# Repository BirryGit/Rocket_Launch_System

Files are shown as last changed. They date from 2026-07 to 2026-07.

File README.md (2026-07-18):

# Rocket Launch System
## What this is
This is a system built to launch mid-powered rockets. The system includes an electronic launch box and a rail for guidance. This project is as simple as possible without compromising look or features.
## Why I built it
I am very nearly finished with my mid-powered rocket build. The rocket kit is called Forte. The problem is launching. I need an electric launch system to set off the electric igniter fuse, and I need a rail to guide the rocket until the fins can take over.
## How to launch
The rocket is put in the slot at the end of the rail, then the 30 ft wire is connected to the rocket's fuse. Once you check the continuity LED, you can flip all of the switches and press the launch buttons! 

## BOM
| Name | Use | Quantity | Cost | Link |
| --- | --- | --- | --- | --- |
| M5 Assorted | Connect things | 19 | 1 | [View item](https://www.amazon.com/Fgruh-272PCS-Washers-Assortment-Assorted/dp/B0FGV561HZ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) |
| M5 T-nuts | Connect things to the extrusion | 17 | 1 | [View item](https://www.amazon.com/dp/B07FPLZXTF?th=1) |
| M5 threaded inserts | Add Threads to 3D printed parts | 3 | 1 | [View item](https://www.amazon.com/Fgruh-272PCS-Washers-Assortment-Assorted/dp/B0FGV561HZ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) |
| M5 washers | For connecting blast deflector | 2 | 1 | [View item](https://www.amazon.com/Fgruh-272PCS-Washers-Assortment-Assorted/dp/B0FGV561HZ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) |
| 3/8-16 x 4 in bolts - Full thread | For leveling feet | 4 | -- | Hardware Store |
| 3/8-16 nut | Feet | 8 | -- | Hardware Store |
| 608 bearings | For smooth feet | 4 | 7 | [View item](https://www.amazon.com/dp/B09PKD8QZZ?th=1) |
| 8 mm rod sections 1 in | For feet | 4 | -- | -- |
| Aluminum extrusion (6 ft, 1010) | Vertical launch rail | 1 | 27 | [View item](https://www.automationdirect.com/adc/shopping/catalog/structural_frames_-z-_rails/t-slotted_rails/1010c) |
| Aluminum extrusion (4 ft, 1010) | Base Piece | 1 | 17 | [View item](https://www.automationdirect.com/adc/shopping/catalog/structural_frames_-z-_rails/t-slotted_rails/1010c) |
| Aluminum extrusion (2 ft, 1010) | Base Piece | 2 | 8 | [View item](https://www.automationdirect.com/adc/shopping/catalog/structural_frames_-z-_rails/t-slotted_rails/1010c) |
| Angle brackets | Frame assembly | 8 | 13 | [View item](https://www.amazon.com/gp/product/B0D3DK2K5F?smid=A2UEOQRRCN7NSU&th=1) |
| Epoxy | Gluing | 1 | -- | -- |
| Metal Plate | Blast Deflection | 1 | -- | -- |
| Pelican Case | Electronics Enclosure | 1 | 30 | [View item](https://www.harborfreight.com/2800-weatherproof-protective-case-medium-black-64551.html) |
| Perfboard | Circuit Organization | 1 | 9 | [View item](https://www.amazon.com/gp/product/B0G4QTPVZ8?smid=A291JS3CHS1ENH&psc=1) |
| Guarded toggle switches | Arming Switch | 2 | 17 | [View item](https://www.amazon.com/gp/product/B07T6XJF1T?smid=AVZNWT0O79W01&th=1) |
| Illuminated momentary switches | Launching Switch | 2 | 8 | [View item](https://www.amazon.com/gp/product/B07FKK2CP5?smid=A1THAZDOWP300U&th=1) |
| Latching key switch | Arming Switch | 1 | 13 | [View item](https://www.amazon.com/gp/product/B07L5D7TXF/ref=ox_sc_saved_title_4?smid=A1POY47GM797OI&psc=1) |
| LED | Continuity LED | 1 | 1 | [View item](https://www.amazon.com/300-Pcs-LED-Diode-Assortment/dp/B0F38LJDJB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) |
| Wire | Connecting Stuff | As Needed | -- | [View item](https://www.amazon.com/Fermerry-Stranded-Electric-Tinned-Copper/dp/B089CQHRDT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) |
| Heat-shrink tubing | Insulating wires | As Needed | -- | [View item](https://www.amazon.com/Ginsco-580-pcs-Assorted-Sleeving/dp/B01MFA3OFA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) |
| Solder | Connecting Wires | As Needed | -- | [View item](https://www.amazon.com/Twocorn-no-wash-tin-Lead-Electric-Soldering/dp/B0CP7QHFL6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) |
| 18650 lithium-ion cells | Power supply | 3 | 4 | [View item](https://www.18650batterystore.com/collections/18650-batteries) |
| 3S battery holder/pack | Holding Batteries | 1 | 7 | [View item](https://www.amazon.com/dp/B07KD9JLH3) |
| 3S protection board | Protect Batteries | 1 | 8 | [View item](https://www.amazon.com/gp/product/B07J9NXQ6W?smid=A1IU4FC9F8Y7P1&psc=1) |
| 5 A automotive fuse | Protect Batteries | 1 | 7 | [View item](https://www.amazon.com/182PCS-Fuses-Assortment-Professional-Automotive/dp/B0CRVF1N2S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) |
| 12 AWG two-conductor cable 30 ft | Connecting to Rocket | 1 | 30 | [View item](https://www.amazon.com/gp/product/B0D9Q3T2N2?smid=A2WDNWBHGNQ6N1&th=1) |

# Pictures
Random_Drawing_Test_2026-Jul-08_02-21-21AM-000_CustomizedView4419025138
Random_Drawing_Test_2026-Jul-08_02-35-28AM-000_CustomizedView16103205783_png
Random_Drawing_Test_2026-Jul-08_02-34-44AM-000_CustomizedView13111556628_png
Random_Drawing_Test_2026-Jul-08_02-22-50AM-000_CustomizedView19276960031_png
Random_Drawing_Test_2026-Jul-08_02-22-06AM-000_CustomizedView41604805889_png
knob_Foot_2026-Jul-06_04-47-25AM-000_CustomizedView34800159218_png

Rocket_Box_2026-Jul-13_03-50-51AM-000_CustomizedView18278803360_png
Rocket_Box_2026-Jul-13_03-42-50AM-000_CustomizedView28827289038_png
Rocket_Box_2026-Jul-13_03-42-22AM-000_CustomizedView5518473478_png
Rocket_Box_2026-Jul-13_03-41-57AM-000_CustomizedView34251778762_png

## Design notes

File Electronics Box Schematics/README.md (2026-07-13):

# Bill Of Materials
- Perfboard
- 12 Gauge Wire, 2 Conductors, Copper Wire 30 ft
- 3S 12V 10A 18650 Lithium Battery Protection Board
- 5A Automotive Fuse
- 2 Momentary LED Switches
- 2 aircraft Guard Safety Switches.
- 1 Latching Key Switch
- Soldering Equipment
- Extra Wire for Connecting Switches (Can be smaller)

# Wiring
Wire according to this schematic. The launch fuse is denoted by an LED.
Annotated
Rocket_Schematic

The number of switches on the left will depend on the number of toggle switches you have. There will always be two momentary switches in order to comply with rocketry laws. The other requirement is for a continuity LED to show if the fuse is making a connection. That is the highest LED that is wired straight through the igniter and a resistor. There needs to be a resistor to stop the fuse from going off prematurely. The LEDS built into the buttons are all wired to common ground. The lights on the momentary switch act as an armed indicator. The last law requirement is that you must be a certain distance from the launch. 30 ft of 12-gauge wire handles that. It has to be thick so as not to cause too much voltage drop.

## Power Source
I used 3 18650 batteries connected to a management board that will safely output 12V. I used a 5A automotive fuse to protect the circuit. It is also important to insulate the board overall to stop shorts. If you wanted to, you could also add a voltage tester in parallel, but I didn't do that.

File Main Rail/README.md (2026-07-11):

# Instructions
Things needed for this part of the build
- 1 X 6ft 10 10 Aluminum Extrusion
- 1 X 4ft 10 10 Aluminum Extrusion
- 2 X 2ft 10 10 Aluminum Extrusion
- 4 X Feet Assemblies
- 8 X 10 10 Angle Brackets
- 16 M5 Bolts
- 16 M5 T Nuts
- 1 X Blast Deflector Assembly
- 1 3/8 tap

## Steps
1. Drill and tap holes into 2ft and 4ft extrusions (One in 2ft and two in 4ft) (Close to the end)
2. Connect the bolt of the feet to the thread
3. Epoxy the end of the bolt into the nut of the foot
4. Connect 2ft and 4ft extrusions in an X shape using the angle brackets, bolts, and nuts
5. Connect the main rod in the same way, directly up from the X
  Updated Rocket Launcher v15
  -  (Use bolts in every hole)

6. Make sure the blast deflector is securely installed

# Renderings

Random_Drawing_Test_2026-Jul-08_02-35-28AM-000_CustomizedView16103205783_png
Random_Drawing_Test_2026-Jul-08_02-34-44AM-000_CustomizedView13111556628_png
Random_Drawing_Test_2026-Jul-08_02-22-50AM-000_CustomizedView19276960031_png
Random_Drawing_Test_2026-Jul-08_02-22-06AM-000_CustomizedView41604805889_png
Random_Drawing_Test_2026-Jul-08_02-21-21AM-000_CustomizedView4419025138

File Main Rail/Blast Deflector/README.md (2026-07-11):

# Parts Needed
- 1 Metal Plate with holes
- 1 3D printed Holder
- 3 M5 * 12
- 3 M5 * 8 ish threaded inserts
- 2 M5 Washers
- 1 M5 T nut

# Assembly

1. Insert inserts into two angled holes
2. Screw M5 bolt into hole without insert
3. Screw on T nut lightly
4. Slide Printed Piece down extrusion
5. Once Holder is in position tighten down bolt to keep in place
6. Screw metal plate in with bolts and washers

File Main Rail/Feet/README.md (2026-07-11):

# Parts Needed for each foot
- 1 608 bearing
- 1 about an inch of 8 mm rod (Mine came from an Ender 3 threaded rod)
- 1 3/8 - 16 by 4in Bolt
- Epoxy
- 1 Printed Knob
- 1 Printed Bearing to Bolt
- 1 Printed Rod to Foot
- 1 Printed Foot Part

# Instructions
1. Print pieces without supports
2. Epoxy bolt into knob 3d print
3. Don't Epoxy Bolt until final install
4. Epoxy Bearing into 3d print
5. Press the printed adapter into the printed foot
6. Epoxy the rod into the adapter and bearing (Do not get Epoxy in the bearing!!)

https://github.com/user-attachments/assets/53609e48-8a4e-4a8f-99e5-f7d9c65818e1

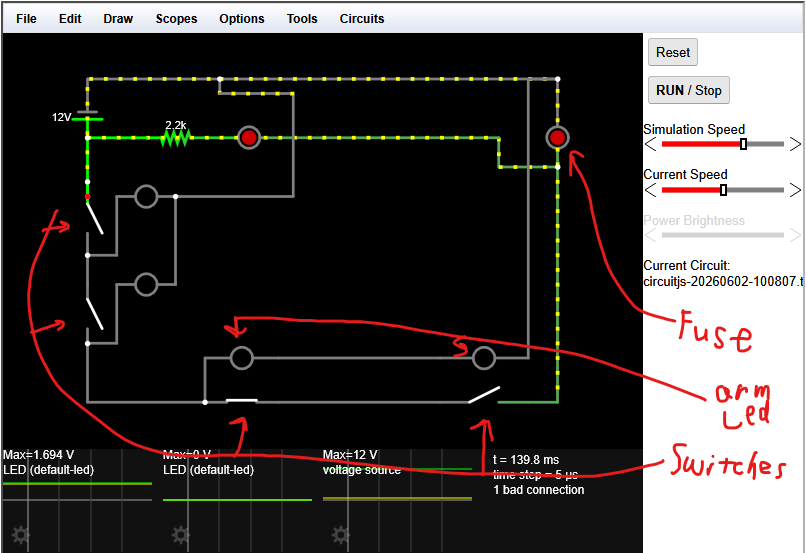
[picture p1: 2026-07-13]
Electronics Box Schematics/Rocket_Schematic.png

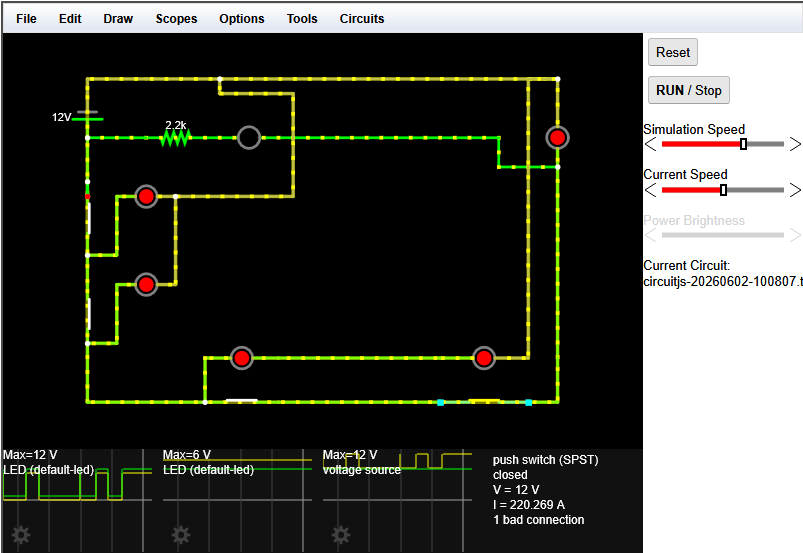
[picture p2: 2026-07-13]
Electronics Box Schematics/Screenshot 2026-07-12 175346.png

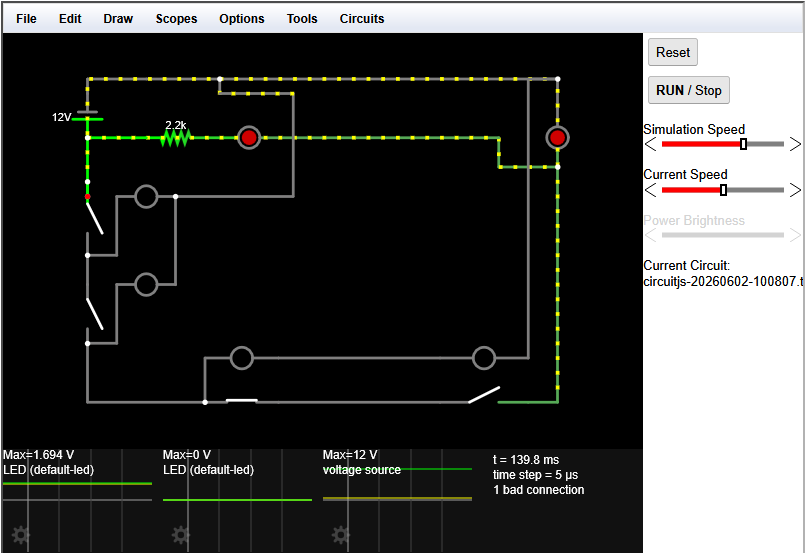
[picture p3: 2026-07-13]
Electronics Box Schematics/Screenshot 2026-06-30 191315.png

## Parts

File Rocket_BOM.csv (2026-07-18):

Name | Use | Quantity | Cost | Link
M5 Assorted | Connect things | 19 | 1 | https://www.amazon.com/Fgruh-272PCS-Washers-Assortment-Assorted/dp/B0FGV561HZ
M5 T-nuts | Connect things to the extrusion | 17 | 1 | https://www.amazon.com/dp/B07FPLZXTF?th=1
M5 threaded inserts | Add Threads to 3D printed parts | 3 | 1 | https://www.amazon.com/Fgruh-272PCS-Washers-Assortment-Assorted/dp/B0FGV561HZ
M5 washers | For connecting blast deflector | 2 | 1 | https://www.amazon.com/Fgruh-272PCS-Washers-Assortment-Assorted/dp/B0FGV561HZ
3/8-16 x 4 in bolts – Full thread | For leveling feet | 4 | -- | Hardware Store
3/8-16 nut | Feet | 8 | -- | Hardware Store
608 bearings | For smooth feet | 4 | 7 | https://www.amazon.com/dp/B09PKD8QZZ?th=1
8 mm rod sections 1 in | For feet | 4 | -- | --
Aluminum extrusion (6 ft, 1010) | Vertical launch rail | 1 | 27 | https://www.automationdirect.com/adc/shopping/catalog/structural_frames_-z-_rails/t-slotted_rails/1010c
Aluminum extrusion (4 ft, 1010) | Base Piece | 1 | 17 | https://www.automationdirect.com/adc/shopping/catalog/structural_frames_-z-_rails/t-slotted_rails/1010c
Aluminum extrusion (2 ft, 1010) | Base Piece | 2 | 8 | https://www.automationdirect.com/adc/shopping/catalog/structural_frames_-z-_rails/t-slotted_rails/1010c
Angle brackets | Frame assembly | 8 | 13 | https://www.amazon.com/gp/product/B0D3DK2K5F?smid=A2UEOQRRCN7NSU&th=1
Epoxy | Gluing | 1 | -- | --
Metal Plate | Blast Deflection | 1 | -- | --
Pelican Case | Electronics Enclosure | 1 | 30 | https://www.harborfreight.com/2800-weatherproof-protective-case-medium-black-64551.html
Perfboard | Circuit Organization | 1 | 9 | https://www.amazon.com/gp/product/B0G4QTPVZ8?smid=A291JS3CHS1ENH&psc=1
Guarded toggle switches | Arming Switch | 2 | 17 | https://www.amazon.com/gp/product/B07T6XJF1T?smid=AVZNWT0O79W01&th=1
Illuminated momentary switches | Launching Switch | 2 | 8 | https://www.amazon.com/gp/product/B07FKK2CP5?smid=A1THAZDOWP300U&th=1
Latching key switch | Arming Switch | 1 | 13 | https://www.amazon.com/gp/product/B07L5D7TXF/ref=ox_sc_saved_title_4?smid=A1POY47GM797OI&psc=1
LED | Continuity LED | 1 | 1 | https://www.amazon.com/300-Pcs-LED-Diode-Assortment/dp/B0F38LJDJB
Wire | Connecting Stuff | As Needed | -- | https://www.amazon.com/Fermerry-Stranded-Electric-Tinned-Copper/dp/B089CQHRDT
Heat-shrink tubing | Insulating wires | As Needed | -- | https://www.amazon.com/Ginsco-580-pcs-Assorted-Sleeving/dp/B01MFA3OFA
Solder | Connecting Wires | As Needed | -- | https://www.amazon.com/Twocorn-no-wash-tin-Lead-Electric-Soldering/dp/B0CP7QHFL6
18650 lithium-ion cells | Power supply | 3 | 4 | https://www.18650batterystore.com/collections/18650-batteries
3S battery holder/pack | Holding Batteries | 1 | 7 | https://www.amazon.com/dp/B07KD9JLH3
3S protection board | Protect Batteries | 1 | 8 | https://www.amazon.com/gp/product/B07J9NXQ6W?smid=A1IU4FC9F8Y7P1&psc=1
5 A automotive fuse | Protect Batteries | 1 | 7 | https://www.amazon.com/182PCS-Fuses-Assortment-Professional-Automotive/dp/B0CRVF1N2S
12 AWG two-conductor cable 30 ft | Connecting to Rocket | 1 | 30 | https://www.amazon.com/gp/product/B0D9Q3T2N2?smid=A2WDNWBHGNQ6N1&th=1

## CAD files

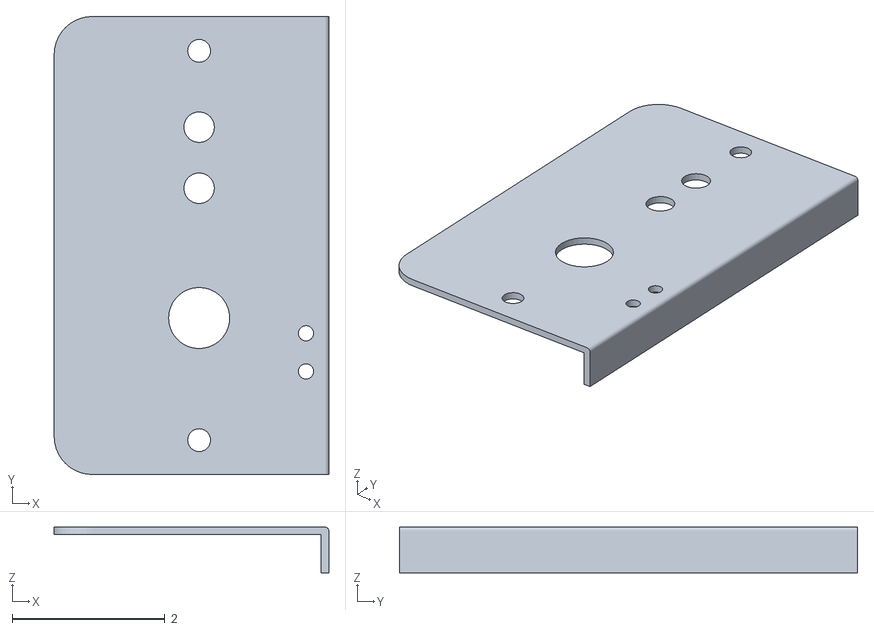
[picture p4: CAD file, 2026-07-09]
Electronics Box 3D Models/Plate_General_Model.stl
3.60 x 6.00 x 0.6

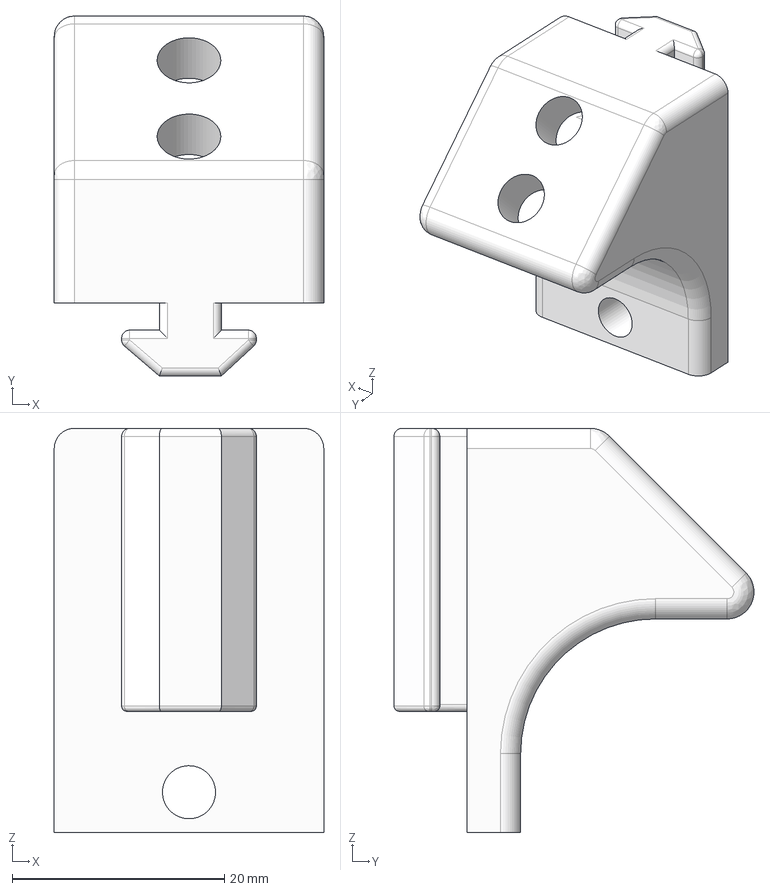
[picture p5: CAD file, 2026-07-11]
Main Rail/Blast Deflector/Blast Deflector Holder v1.step
25.4 x 33.9 x 38.1 mm

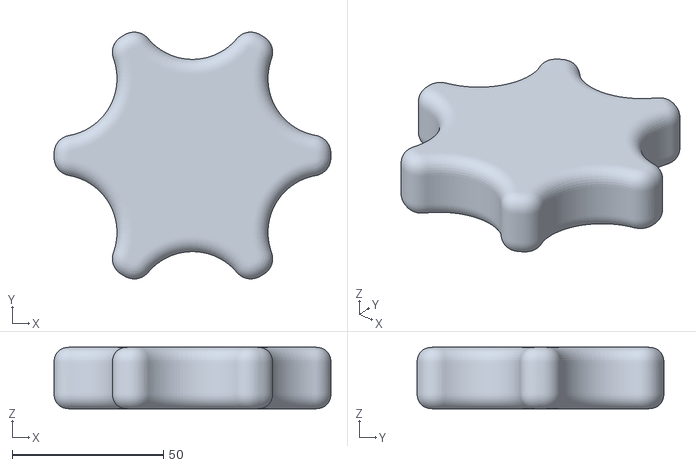
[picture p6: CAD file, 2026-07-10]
Main Rail/Feet/Knob.stl
91.4 x 81.5 x 20.3

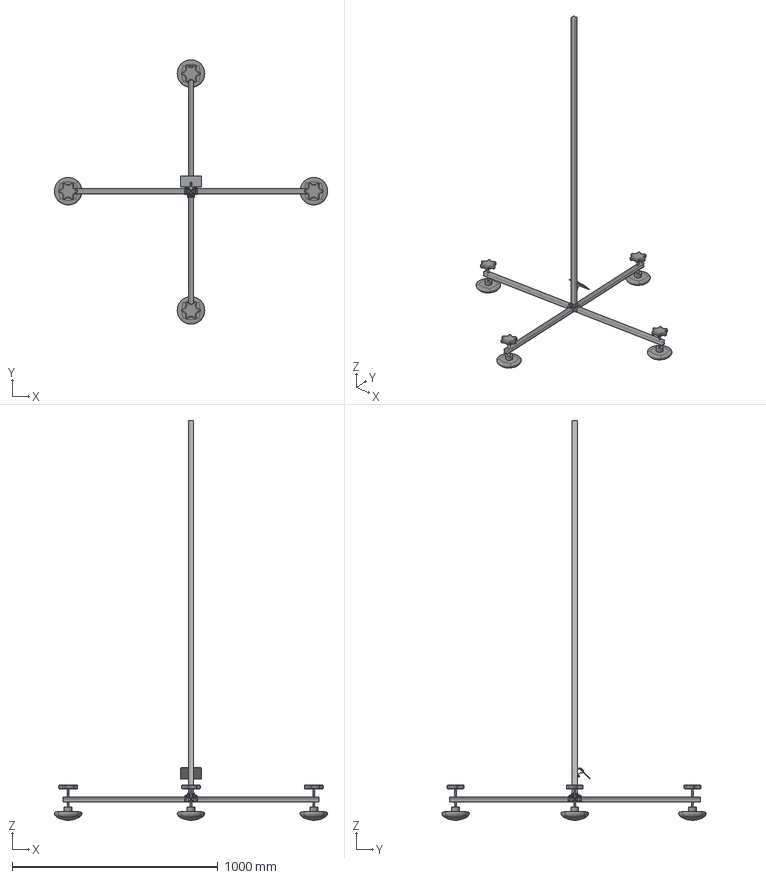
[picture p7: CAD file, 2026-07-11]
Main Rail/Rocket Launch Rail.step
1327.7 x 1284.8 x 1943.6 mm
47065T563_T-Slotted Framing
47065T563_T-Slotted Framing_1
47065T563_T-Slotted Framing_2 x 2
28-600-1Inch x 8
BSHCS ASME B18.3.1M - M5x0.8 x 12 Steel Grade 2 Plain
FPW JIS B 1256 - 5 Steel 100 HV Plain
BSHCS ASME B18.3.1M - M5x0.8 x 12 Steel Grade 2 Black x 3
FPW JIS B 1256 - 5 Steel 100 HV Black x 3
92865A641_Medium-Strength Grade 5 Steel Hex Head Screw x 4
2349K744_Permanently Lubricated Ball Bearing x 4
HN ASME B18.2.2 - 3/8-16 Steel Grade 2H Zinc x 4
Blast Deflector Holder
BSHCS ANSI B18.3.1M - M5x0.8 x 12 Steel Grade 2 Black x 3
BW BS 4320 - M5 E Steel 100 HV Black x 2

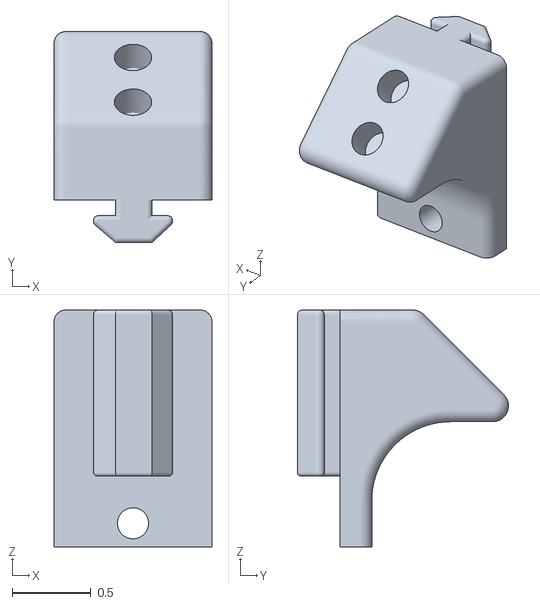
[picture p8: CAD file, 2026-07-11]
Main Rail/Blast Deflector/Blast Plate Print.stl
1.00 x 1.34 x 1.50

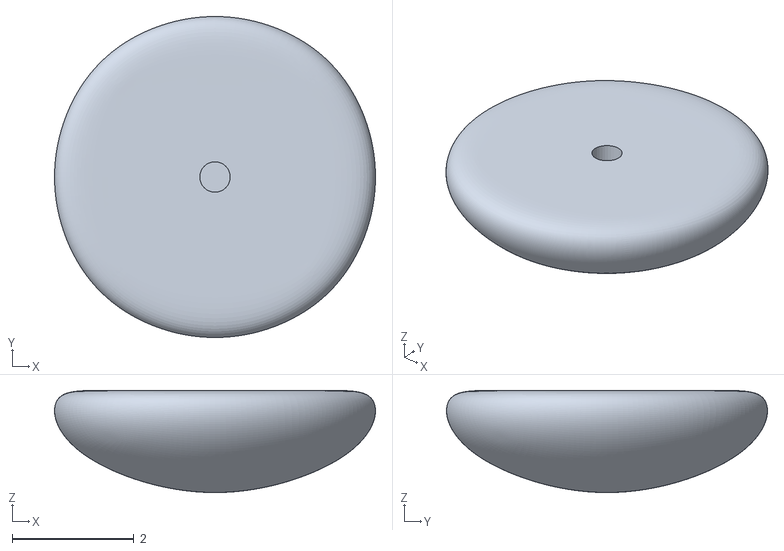
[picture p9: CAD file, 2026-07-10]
Main Rail/Feet/Foot Base.stl
5.27 x 5.27 x 1.68

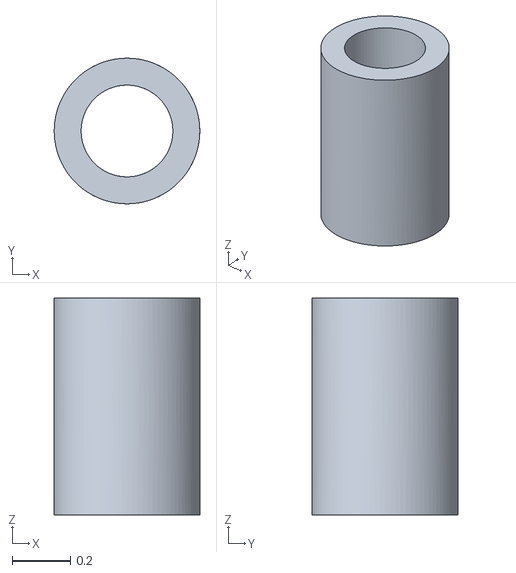
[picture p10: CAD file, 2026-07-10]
Main Rail/Feet/Rod to Foot.stl
0.5 x 0.5 x 0.745

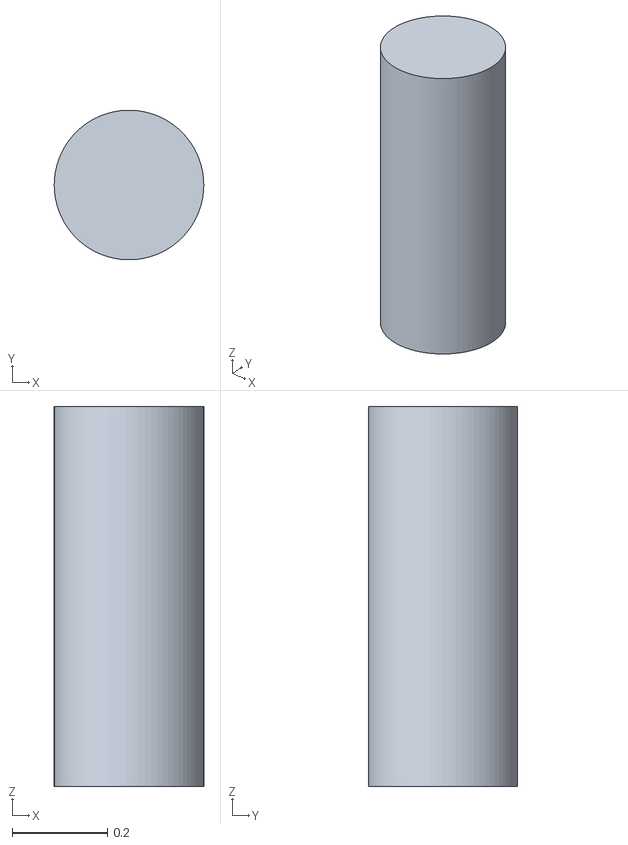
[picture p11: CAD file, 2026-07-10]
Main Rail/Feet/Rod Stand In.stl
0.315 x 0.315 x 0.8

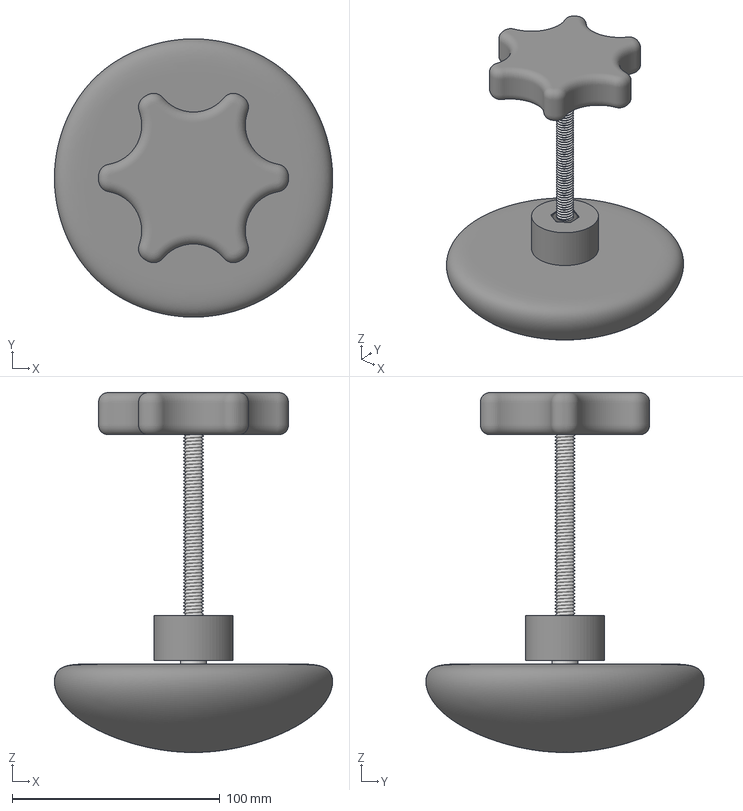
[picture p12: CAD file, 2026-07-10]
Main Rail/Feet/knob Foot.3mf
133.9 x 133.9 x 173.2 mm

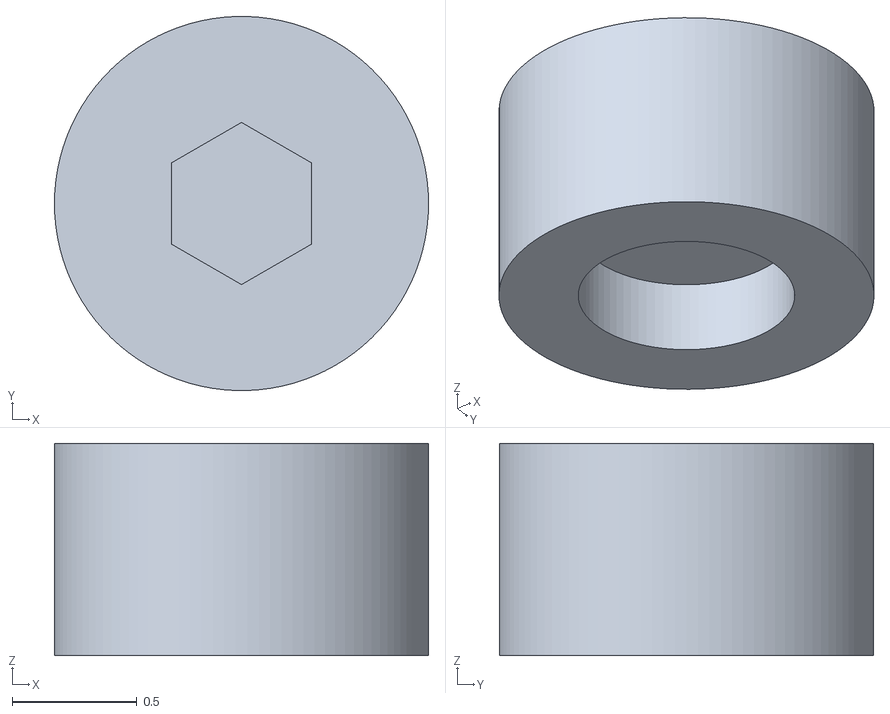
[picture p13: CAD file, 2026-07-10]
Main Rail/Feet/Bearing to Bolt.stl
1.50 x 1.50 x 0.85

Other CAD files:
Main Rail/Blast Deflector/Blast Deflector Holder v1.f3d
Main Rail/Feet/knob Foot.f3z

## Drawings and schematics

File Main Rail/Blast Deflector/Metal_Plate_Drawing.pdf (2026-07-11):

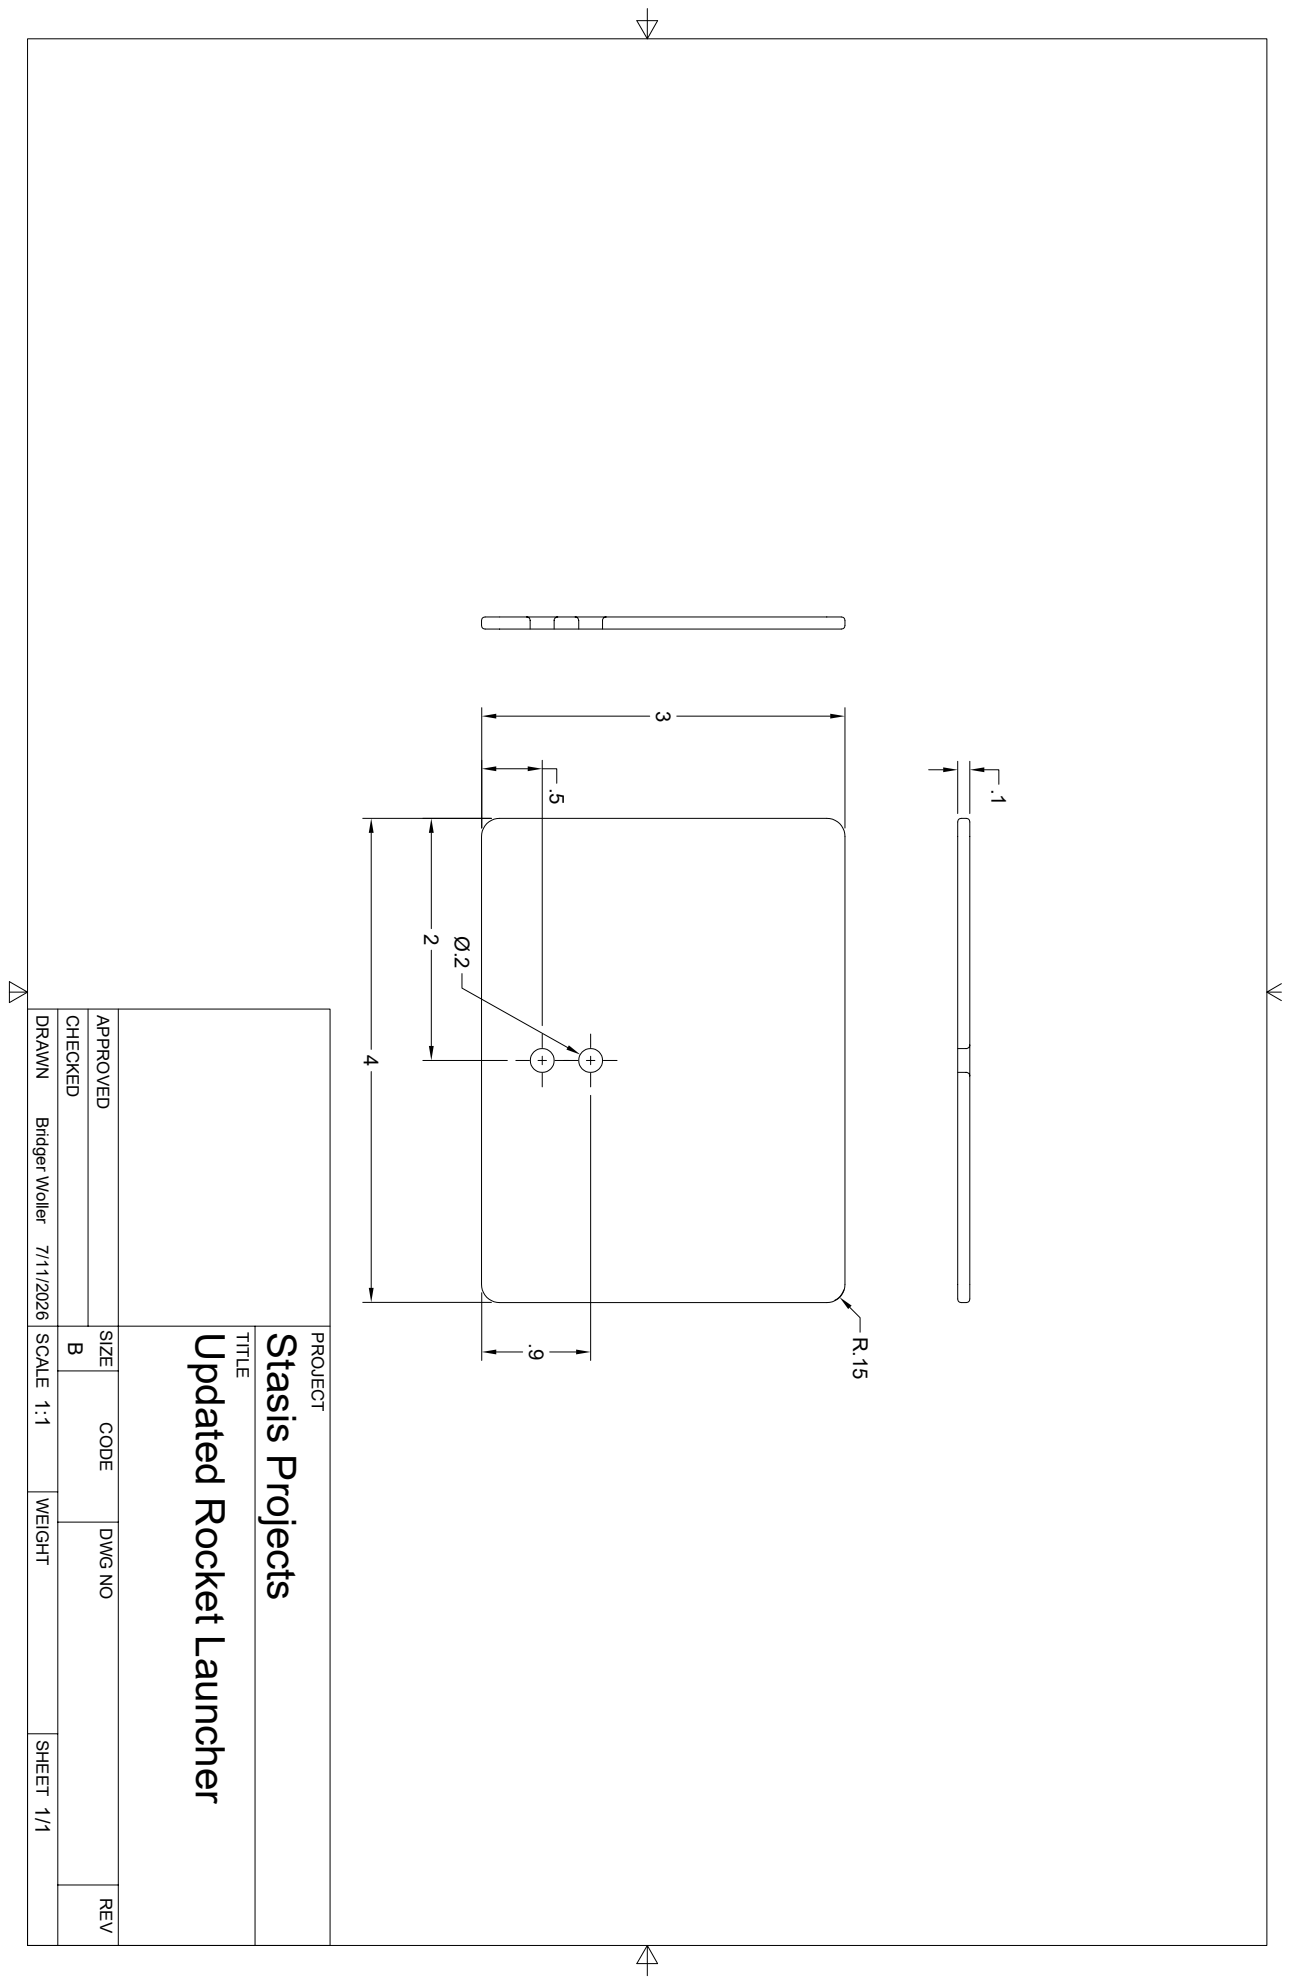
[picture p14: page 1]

TITLE PROJECT DRAWN CHECKED APPROVED SCALE WEIGHT SHEET DWG NO REV CODE SIZE 1/1 1:1 7/11/2026 Bridger Woller BUpdated Rocket Launcher Stasis Projects 4 3 .1 Ø.2 R.15 2 .9 .5

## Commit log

2026-07-09 Added Electronic Box Files
    [Plate_General_Model.stl]
2026-07-10 Added Feet 3d Models
    [Bearing to Bolt.stl, Foot Base.stl, Knob.stl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]
2026-07-11 Add assembly instructions to README.md
    Added assembly instructions for printed parts.
2026-07-11 Added Blast Deflector Files
    [Blast Deflector Holder v1.f3d, Blast Deflector Holder v1.step, Blast Plate Print.stl]
2026-07-11 Enhance README with detailed assembly steps and images
    Updated assembly instructions and added rendering images.
2026-07-11 Added Step Main File
    [Rocket Launch Rail.step]
2026-07-12 Renamed Folder to specify 3D models for box.
    [Plate_General_Model.stl]
2026-07-13 Added BOM, and more information
    Updated the Bill of Materials section for clarity and added details about wire specifications.
2026-07-13 Made ReadMe with everything except BOM
    Expanded project description and added launch instructions, BOM, and images.
2026-07-18 Added BOM
    [Rocket_BOM.csv]
2026-07-18 Added BOM to README
